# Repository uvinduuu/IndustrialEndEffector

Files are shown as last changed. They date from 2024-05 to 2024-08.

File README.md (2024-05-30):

# IndustrialEndEffector
 This project features an industrial end effector for automated pick and place robots with a vacuum gripper. It uses four ToF sensors to accurately measure box yaw and pitch angles. Data is transmitted via Modbus protocol over USB, ensuring seamless integration with robot control panels for precise orientation detection and efficient communication.

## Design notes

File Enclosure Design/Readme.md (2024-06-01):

# Industrial End Effector Enclosure Design

### Initial Approach
The primary challenge was to create an adjustable enclosure compatible with various vacuum gripper sizes. This included:
- Ensuring the TOF sensors could be repositioned.
- Providing a secure attachment method for different gripper designs.
- Balancing sensor movement with mechanical strength.

### Design Challenges and Decisions
However, we encountered several bottlenecks with this adjustable design approach:
- **Variable Vacuum Gripper Sizes:** Vacuum grippers vary significantly in size, necessitating a high degree of adjustability for the TOF sensors.
- **Attachment Method:** We needed a reliable method to attach the end effector to the gripper. Due to the varying designs of grippers, finding a universal attachment method proved difficult.
- **Sensor Movement:** The TOF sensors needed to move in two directions, adding complexity to the design.
- **Mechanical Strength:** The mechanical parts required high strength to ensure durability and stability.

### Final Design
Due to the impracticality of an adjustable design, the final implementation focused on a specific vacuum gripper model:
- **Sensor Placement:** Dedicated mounting places for TOF sensors to avoid interference with the gripper's functionality.
- **PCB Housing:** A separate box for the PCB, securely attachable to the gripper, with easy access to the USB port.
  
Image description

### Demonstration Setup
For demonstration purposes, a box will be printed to showcase the enclosure's design:
- **Sensor Mounting:** TOF sensors mounted on a board spaced 10 cm apart.
- **Enclosure Features:** Air vents for heat dissipation, mounting bosses for PCB, and a separate lid with M3 screws.



## Project Goals
- **High Precision:** Achieve accurate voltage measurements with minimal impact on the circuit under test.
- **Flexibility:** Ensure compatibility with various gripper designs without compromising performance.
- **Reliability:** Provide a stable and durable solution tailored to specific vacuum gripper models.

## How to Use
1. **Connect the Enclosure:** Securely attach the PCB enclosure to the vacuum gripper using the provided nuts.
2. **Interface with Robot Control Panels:** Utilize the USB port for data transmission via Modbus protocol.
3. **Monitor Performance:** Use the LED indicators to check the power status and ensure proper sensor operation.

## Contact
For more information or questions, please contact [mihiruth@gmail.com](mailto:mihiruth@gmail.com).

---

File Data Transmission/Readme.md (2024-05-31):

# Industrial End Effector Transmission Directory

## Overview

The measured data from tof sensors is transmitted to the robot control panel using the Modbus protocol. This provides details on the transmission part of the project, including the hardware components used and the steps for data transmission.

## What is Modbus?

Modbus is a serial communication protocol developed for industrial applications to facilitate communication between electronic devices. It is a widely used protocol in the industry due to its simplicity and reliability. Modbus allows multiple devices to communicate over a single serial connection and supports both serial and TCP/IP communications.

## Why Choose Modbus?

Modbus is chosen for this project because:
- It is a standardized protocol widely used in industrial environments.
- It supports communication over long distances with robust error checking.
- It can easily integrate with various industrial equipment and control systems.

## Hardware Components

### MAX485 TTL to RS485 Converter Module

To transmit data from the ToF sensors to the robot control panel, we use the MAX485 TTL to RS485 MAX485CSA Converter Module. This module converts the TTL level signals from the atmega2560 to RS485, which is suitable for long-distance communication.

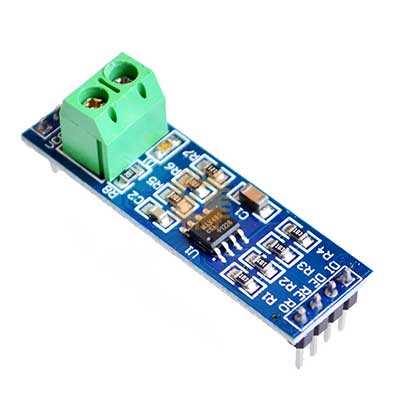
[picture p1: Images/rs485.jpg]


#### How It Happens
- The MAX485 module converts the TTL signals from the atmega2560 to differential RS485 signals.
- RS485 allows for reliable data transmission over long distances in noisy industrial environments.

#### How to Connect
2. **atmega2560 to MAX485 Module:**
   - Connect the appropriate GPIO pins of the atmega2560 (TX and RX pins, usually pins 18 and 19 for serial communication) to the input pins of the MAX485 module (DI and RO pins respectively).
   - Connect the DE (Data Enable) and RE (Receive Enable) pins of the MAX485 module to a digital pin on the atmega2560 to control the direction of data flow.
3. **MAX485 Module to RS485 Bus:**
   - Connect the RS485 output pins (A and B) of the MAX485 module to the RS485 input of the robot control panel.
4. **Power Supply:**
   - Ensure proper power supply connections to the MAX485 module from the atmega2560 or an external source.

### USB to RS485 Communication Module

For debugging purposes, we use a USB to RS485 Communication Module to connect the system to a PC.

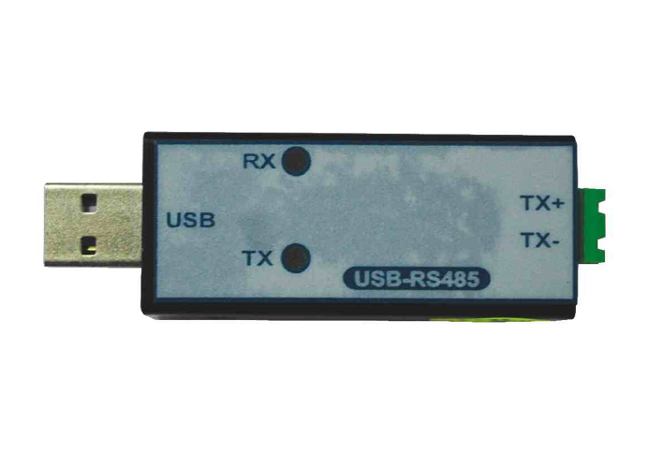
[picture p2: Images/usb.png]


#### How It Works
- The USB to RS485 module converts the USB signals from the PC to RS485 signals.
- This allows the PC to communicate with the RS485 bus, facilitating debugging and testing.

#### Why We Use It
- To monitor and debug the data being transmitted from the sensors to the robot control panel.
- To ensure that the data transmission is working correctly before final integration.

#### How to Connect
1. Connect the RS485 side of the USB to RS485 module to the RS485 bus (parallel connection with MAX485 module).
2. Plug the USB side of the module into the PC.
3. Use a terminal program or Modbus Poll software to monitor the data.

### Modbus Poll Software

For visualization, we use Modbus Poll software, a Modbus master simulator designed to monitor and test Modbus systems.

#### How It Works
- Modbus Poll allows you to send Modbus queries to the devices on the RS485 bus.
- It displays the data received from the devices, enabling real-time monitoring and testing.

#### Why We Use It
- To verify the data being transmitted by the sensors.
- To ensure the integrity and accuracy of the data before it reaches the robot control panel.

#### How to Use
1. Install Modbus Poll software on your PC.
2. Connect the PC to the RS485 bus using the USB to RS485 module.
3. Configure Modbus Poll to match the communication settings of your system (baud rate, parity, etc.).
4. Start the Modbus Poll to monitor and visualize the data.

## Conclusion

Modbus is a reliable and widely-used protocol for industrial communication, making it an excellent choice for transmitting sensor data to the robot control panel. By using the MAX485 converter module and USB to RS485 module, we ensure robust and accurate data transmission. Modbus Poll software further aids in debugging and visualization, ensuring the system functions correctly before deployment.

For more detailed technical information, feel free to contact [me](mailto:uvindukodikara@gmail.com).

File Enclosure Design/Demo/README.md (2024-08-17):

This Setup was developed for the Project Demonstration. Since we couldn't manufacture an actual vacuum gripper, we 3D printed a structure and used it for the demonstration purposes.





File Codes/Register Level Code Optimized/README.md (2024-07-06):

# Register Level Code
## Components
### Main File
- Performs calculations for the distance, pitch, and yaw of objects.
- Coordinates the overall functionality of the system.

### ToF Library
- Interfaces with the VL53L0x Time-of-Flight (ToF) sensor.
- Reads distance values from the ToF sensor.

### UART Library
- Handles serial communication using the UART protocol.
- Facilitates data transmission between the device and the Modbus converter.

### Multi-Distance Library
- Manages the multiplexer to enable the use of multiple ToF sensors.
- Retrieves distance values from several ToF sensors simultaneously.

### Delay Library
- Provides precise delay functionality.
- Ensures timing accuracy within the system.

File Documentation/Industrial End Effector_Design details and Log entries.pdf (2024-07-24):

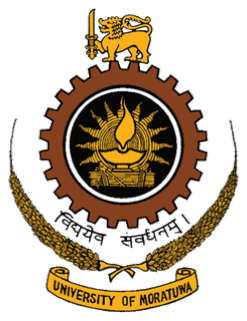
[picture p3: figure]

# University of Moratuwa, Sri Lanka

# Faculty of Engineering

## Department of Electronics and Telecommunication Engineering Semester 4 (Intake 2021)

# EN2160 - Electronic Design Realization

# Industrial End Effector - Design Details

## Group B

Kodikara U.S.S | 210293K
Gunawardane E.R.N.H. | 210200C
Sehara G.M.M. | 210583B
Kodithuwakku J.N. | 210294N

This report is submitted as a partial fulfillment for the module EN2160 - Electronic Design Realization, Department of Electronic and Telecommunication Engineering, University of Moratuwa.

## Contents

1 Comprehensive Design Details | 3
2 Final Code | 11
3 Daily Log Entries | 20

## 1 Comprehensive Design Details

### 1.1 Microcontroller Unit

The end-effector utilizes an ATmega2560 microcontroller to primarily gather readings from four sensors and perform calculations to determine the object’s distance and orientation (yaw and pitch). The ATmega2560’s capability to handle complex tasks and its compatibility with extensive sensor libraries make it an ideal choice for this application.

### 1.1.1 Distance and Orientation Measurement:

In the design of the end-effector, the ATmega2560 microcontroller plays a pivotal role in integrating sensor data and performing complex calculations to determine object distance and orientation. This microcontroller excels in managing multiple time-of-flight sensors through the I2C protocol, utilizing the Adafruit library for seamless sensor interfacing despite its extensive functionality. Here’s a detailed breakdown of its functionalities and implementation:

- Sensor Integration via I2C Protocol:

– The ATmega2560 communicates with four time-of-flight sensors using the I2C protocol, enabling efficient data transmission between the microcontroller and sensors. This protocol is chosen for its simplicity and suitability for connecting multiple sensors over short distances, ensuring reliable and synchronized data acquisition.

- Distance Measurement and Averaging:

– The The microcontroller collects distance readings from four distinct points on the object using the time-of-flight sensors. These readings are averaged to provide a precise measurement of the object’s distance from the end-effector. This averaging process enhances accuracy by mitigating potential outliers or sensor variations.

- Calculation of Pitch and Yaw:

– Using the averaged distance data, the ATmega2560 computes the object’s orientation in terms of pitch and yaw angles. This calculation involves employing inverse tangent equations to translate distance variations into angular measurements, crucial for determining the object’s spatial orientation relative to the end-effector.

- Utilization of Adafruit Library for Sensor Interface:

– The implementation leverages the Adafruit library due to its comprehensive support for sensor interfacing and data handling. Despite its heavyweight nature, the library simplifies the integration of complex sensors with the ATmega2560, streamlining development efforts and ensuring robust sensor data acquisition.

- Data Transfer via Modbus Protocol:

– After completing distance and orientation calculations, the microcontroller transfers the processed data to a Modbus converter. The Modbus protocol facilitates efficient and standardized communication between the microcontroller and external systems or devices, ensuring seamless integration into larger control or monitoring frameworks.

### 1.1.2 Programming the Microcontroller

Programming the ATmega microcontroller using the Unified Program and Debug Interface (UPDI) is a strategically advantageous approach tailored for this application. The UPDI method offers several benefits that are highly pertinent:

- Efficiency in Firmware Management: UPDI facilitates efficient uploading of firmware into the ATmega microcontroller, ensuring smooth and reliable operation of the end-effector system.
- Simplicity and Effectiveness: This programming interface is known for its straightforward implementation and effective debugging capabilities, making it easier to manage and maintain the firmware.
- Streamlined Development Process: UPDI streamlines the development process by enabling quick updates and modifications to the microcontroller’s firmware, crucial for adapting to changing project requirements or improving functionality.
- Future-Proofing and Flexibility: By using UPDI, the system becomes future-proofed, allowing for potential enhancements or adjustments in operational protocols without major hardware changes.

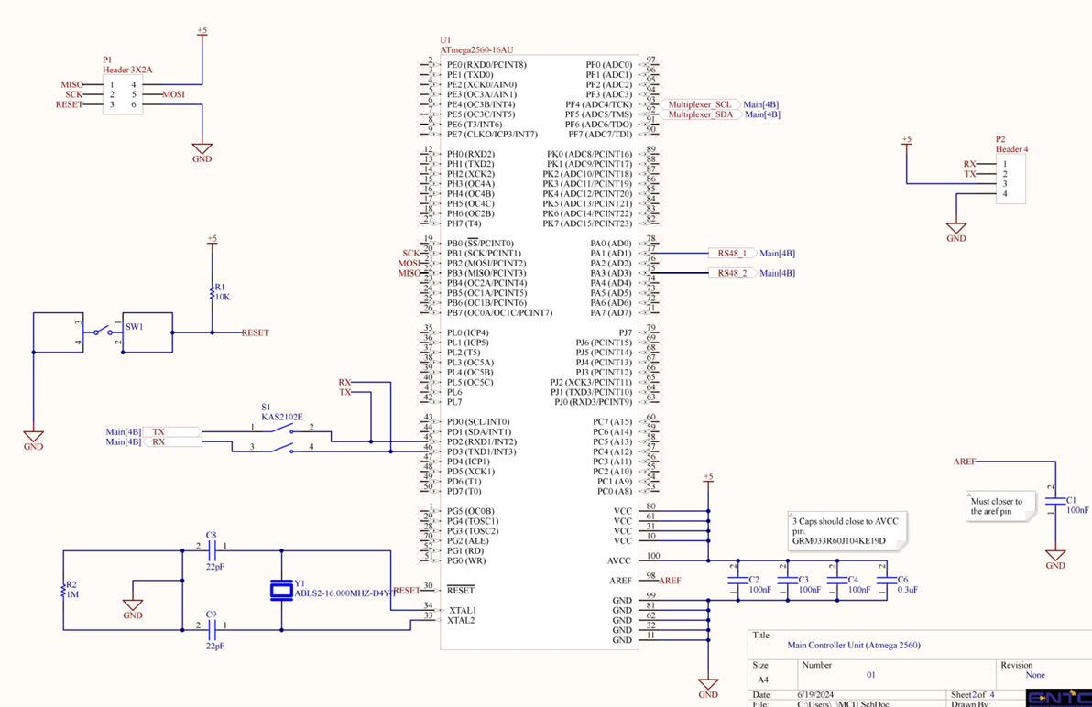
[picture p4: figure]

Figure 1: Schematic of microcontroller connections

### 1.2 Multiplexer

In optimizing the integration of multiple time-of-flight (ToF) sensors with our ATmega2560 microcontroller, we implemented the PCA9546A 1 to 4 multiplexer for streamlined I2C communication.

### 1.2.1 Why a multiplexer?

- Efficient Management of Sensor Connections:

– The PCA9546A allows us to connect up to four sensors to a single pair of SDA and SCL lines from the microcontroller.

– This consolidates multiple I2C connections into a single interface, simplifying the overall wiring layout and reducing the number of required microcontroller pins.

- Minimization of Complexity:

– By using the multiplexer, we streamline the process of interfacing multiple sensors with the microcontroller.

– It eliminates the need for additional I2C buses and complex wiring configurations, which can otherwise complicate the design and increase potential points of failure.

- Reduction of Potential Signal Interference:

– Centralizing sensor connections through the multiplexer helps minimize signal interference and crosstalk between different I2C devices.

– This ensures that data communication between the microcontroller and each sensor remains reliable and unaffected by external electrical noise.

- Enhanced Reliability of Data Acquisition:

– The PCA9546A’s ability to selectively enable communication with each sensor via its independent channels ensures reliable data acquisition.

– It provides precise control over which sensor is actively communicating with the microcontroller at any given time, optimizing data throughput and system responsiveness.

### 1.2.2 Hardware Components

The PCA9546A is a versatile I2C multiplexer designed to enable communication with multiple I2C devices using a single microcontroller interface. It features four independent channels that can be selected via control registers, effectively routing data and clock signals to different I2C buses connected to various sensors. This flexibility makes it ideal for applications requiring efficient management of multiple I2C devices without the need for additional microcontroller pins or complex wiring.

How it is connected

- atmega2560 to multiplexer

– The main SDA (data) and SCL (clock) lines from the ATmega2560 microcontroller are connected directly to the PCA9546A multiplexer.

- multiplexer to the ToF sensors

– The PCA9546A multiplexer features four independent channels, each capable of connecting to a separate I2C bus.

– Each ToF sensor module is connected to one of these channels on the multiplexer, establishing a dedicated communication path between the microcontroller and each sensor.

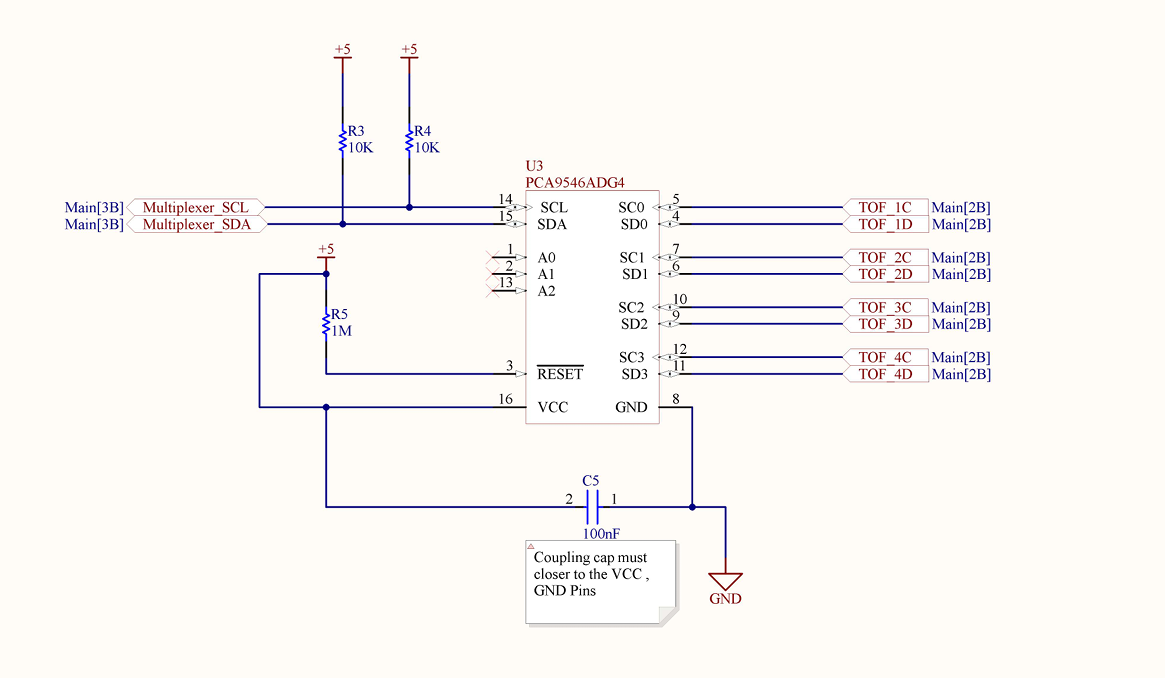
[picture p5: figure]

Figure 2: Schematic of PCA9546A connections

### 1.3 Time of Flight Sensors

### 1.3.1 Implementation of the Time of Flight Sensors

For the end-effector application, selecting VL53L0X Time-of-Flight (ToF) sensors was crucial for achieving accurate distance measurements from four distinct points on objects. These sensors, renowned for their precision and ease of integration, utilize the I2C communication protocol for seamless interfacing with our ATmega2560 microcontroller. By directly connecting these sensors to a PCA9546A multiplexer, we efficiently manage communication channels while maintaining high measurement accuracy.

### 1.3.2 Why VL53L0X?

he VL53L0X ToF sensor module is a compact and highly accurate device designed specifically for distance measurement applications. It operates by emitting short pulses of infrared light and measuring the time it takes for these pulses to reflect off a target surface and return to the sensor. This time-of-flight measurement directly correlates to the distance between the sensor and the object being measured. The sensor employs advanced algorithms within its internal processing unit to calculate distances with exceptional precision, achieving resolutions down to millimeters. This method ensures consistent and reliable performance across diverse environmental conditions, making the VL53L0X ideal for applications requiring precise and robust distance measurements. Some advantages of the implementation of VL53L0X are,

- High Accuracy: Provides precise distance measurements with resolutions as fine as millimeters, ensuring reliable data for critical applications.
- Compact Size: Small form factor makes it suitable for integration into compact or spaceconstrained devices and systems.
- Wide Measurement Range: Offers a wide range of measurement distances, accommodating diverse application needs from short to long distances.
- Easy Integration: Supports simple integration into existing systems with straightforward I2C communication protocol and user-friendly interfaces.

### 1.3.3 Hardware Connections

- Direct Connection to Multiplexer Channels:

– Each VL53L0X sensor module is connected directly to one of the output channels of the PCA9546A multiplexer.

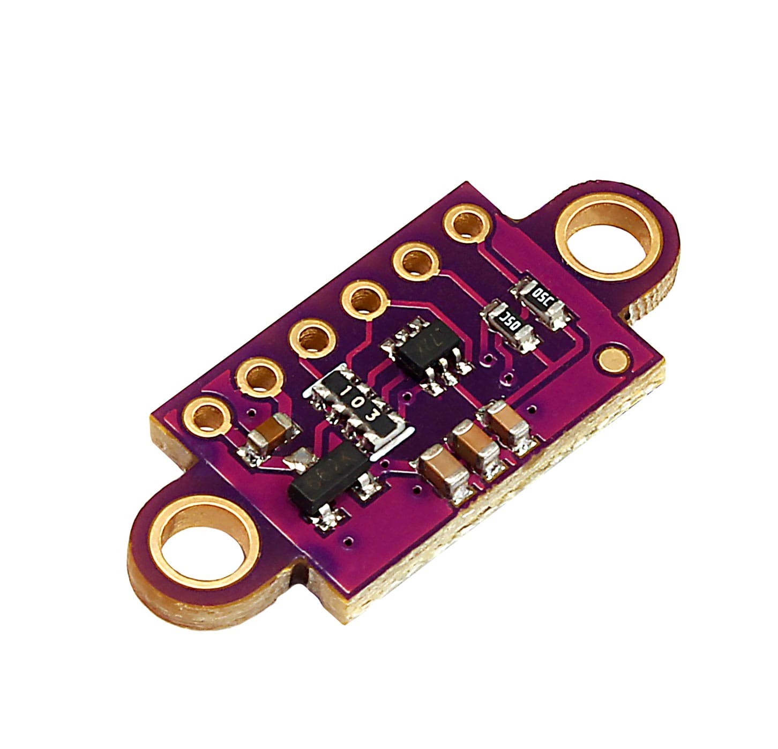
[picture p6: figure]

Figure 3: VL53L0X Sensor Module

### 1.4 Modbus Transmitter

In the development of an industrial end effector, particularly for a vacuum gripper, precise and reliable transmission of sensor data is crucial. Our project employs four Time of Flight (ToF) sensors to measure pitch and yaw angles, with the data transmitted to the robot control panel using the Modbus protocol. This section details the transmission component of the project, covering hardware and data transmission steps.

### 1.4.1 Implementation of Modbus Communication

Modbus is a serial communication protocol designed for industrial applications, facilitating communication between electronic devices. Its simplicity, reliability, and support for both serial and TCP/IP communications make it an excellent choice for our project.

### 1.4.2 Why Choose Modbus?

- Standardization: Widely used in industrial environments.
- Distance and Reliability: Supports long-distance communication with robust error checking.
- Integration: Easily integrates with various industrial equipment and control systems.

### 1.4.3 Hardware Components

MAX485 TTL to RS485 Converter Module
To transmit data from the ToF sensors to the robot control panel, we use the MAX485 TTL to RS485 MAX485CSA Converter Module. This module converts TTL level signals from the sensors to RS485, suitable for long-distance communication.

How It Works

The MAX485 module converts the TTL signals from the sensors to differential RS485 signals, enabling reliable data transmission over long distances in noisy industrial environments.

How to Connect

- atmega2560 to MAX485 Module:

– Connect the appropriate GPIO pins of the atmega2560 (TX and RX pins, usually pins 18 and 19 for serial communication) to the input pins of the MAX485 module (DI and RO pins respectively).

– Connect the DE (Data Enable) and RE (Receive Enable) pins of the MAX485 module to a digital pin on the Arduino Mega to control the direction of data flow.

- MAX485 Module to RS485 Bus:

– Connect the RS485 output pins (A and B) of the MAX485 module to the RS485 input of the robot control panel.

- Power Supply:

– Ensure proper power supply connections to the MAX485 module from the Arduino Mega or an external source.

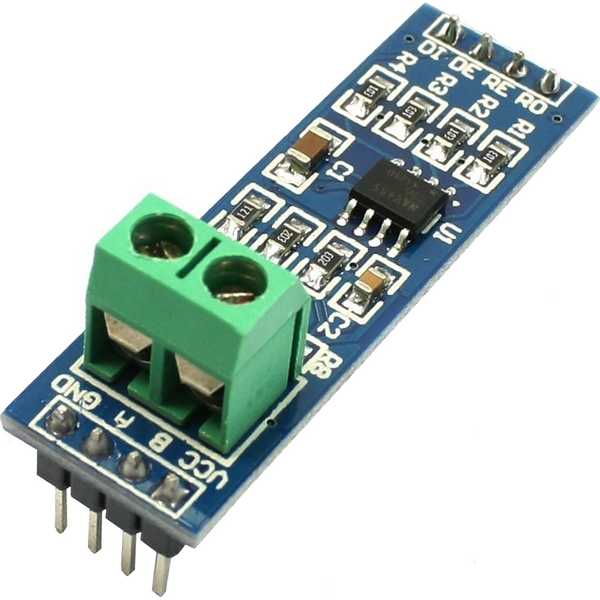
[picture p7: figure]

Figure 4: MAX485 TTL to RS485 Converter Module

### 1.5 Testing and Demonstration

In the end effector, we utilize the Modbus protocol to communicate with the robot arm. However, for testing and debugging purposes, we need to display the calculated pitch and yaw angles from our end effector. Since these values are transmitted using the Modbus protocol, they cannot be directly observed on the computer interface. Therefore, we employ an RS485 to USB converter module along with Modbus Poll software. This setup is essential solely for demonstration and testing purposes.

### 1.5.1 USB to RS485 Communication Module

Functionality
The USB to RS485 Communication Module is essential for converting Modbus protocol signals from the RS485 bus into a format compatible with USB, enabling data display and interaction on a computer.

Operational Mechanism

- Signal Conversion:

– Converts Modbus protocol signals from RS485 to USB format, facilitating direct communication between the RS485 bus and a computer.

- Display Compatibility:

– Enables the display and interaction of received data from RS485 devices on a computer interface via USB port of the computer.

- Diagnostic and Debugging Tool:

– Used extensively for monitoring and debugging data transmissions between sensors, the end effector, and the computer; ensuring clear and accurate display of data received via Modbus protocol on a computer screen.

Connection Procedure:

- Connect the RS485 side of the ’USB to RS485 module’ to the ’MAX485 TTL to RS485 Converter Module’.
- Plug the USB side of the module into a computer, establishing a direct interface for data display and interaction.

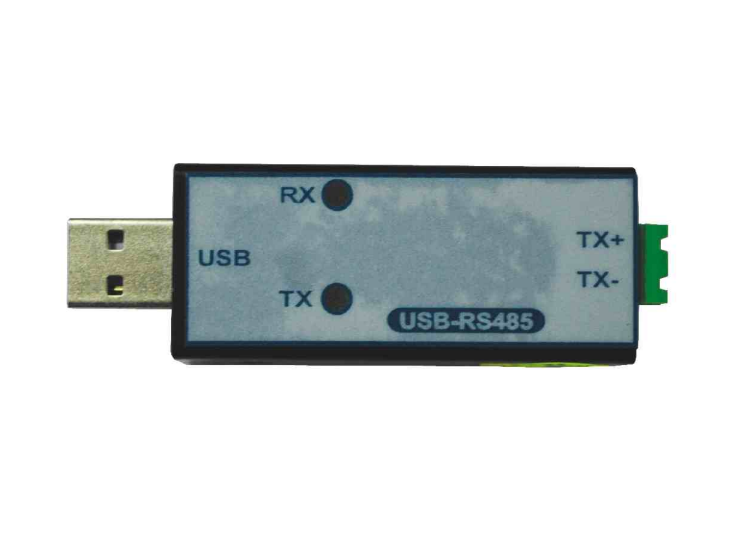
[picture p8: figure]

Figure 5: USB to RS485 Communication Module

### 1.5.2 Modbus poll software

Functionality
Modbus Poll software serves as a Modbus master simulator designed for monitoring and testing Modbus systems. It facilitates visualization and interaction with data exchanged over the RS485 bus.

Operational Mechanism

- Data Monitoring:

– Allows users to send Modbus queries to devices connected on the RS485 bus.

- Real-time Display:

– Displays data received from connected devices, enabling real-time monitoring and testing of Modbus communications.

- Diagnostic and Debugging Tool:

– Essential for verifying data accuracy, integrity, and transmission reliability before it reaches the robot control panel, ensuring the data transmitted by sensors is accurate and consistent.

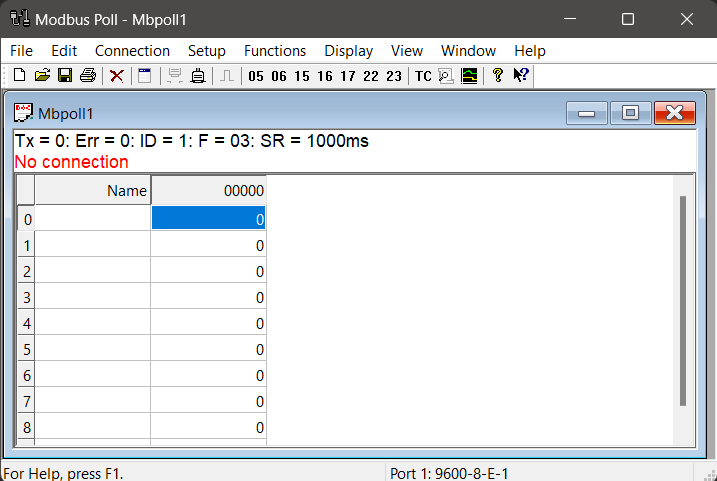
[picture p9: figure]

Figure 6: Modbus Poll Software

## 2 Final Code

# include < avr / io .h >

# include " delay .h"

# include " uart .h"

# include "TWI.h"

# include "ToF.h"

# include " multi_distance .h"

// // below values should be configured
float dv = 41; // vertical distance between the ToF sensors
float dhu = 76; // horizontal distance between the upper ToF sensors float dhd = 76; // horizontal distance between the lower ToF sensors

// // below values are read and calculated
float relativeDistance ;
float dlu ; // left upper ToF sensor distance float dru ; // right upper ToF sensor distance
float dld ; // left down ToF sensor distance
float drd ; // right down ToF sensor distance
float thetaP ; // pitch angle ( angle around the horizontal axis ) float thetaY ; // yaw angle ( angle around the vertical axis )

int main () {
init_uart () ; // Intializing the Serial communication with UART protocol i2c_init () ; // Intializing TWI
setID () ; // Intializing the multiplexer and the ToF sensors
init_rs485 () ; // Initialize RS485 pins

while (1) {
dlu = 0;
dru = 0;
dld = 0;
drd = 0;

for (int i =0; i <5; i ++) { // Implementation of the moving average filter dlu += sensor_1 () - 5;
dru += sensor_2 () ;
dld += sensor_3 () ;
drd += sensor_4 () - 4;
delay_ms (10) ;

}

dlu = dlu /5;
dru = dru /5;
dld = dld /5;
drd = drd /5;

relativeDistance = ( dlu + dru + dld + drd ) /4;

thetaP = 0.5* atan (( dlu - dld ) / dv ) + 0.5* atan (( dru - drd ) / dv ) ; // Calculating the Pitch
thetaY = 0.5* atan (( dru - dlu ) / dhu ) + 0.5* atan (( drd - dld ) / dhd ) ; // Calculating the Yaw thetaP = degrees ( thetaP ) ;
thetaY = degrees ( thetaY ) ;

trans_string (" Relative Distance : ") ; trans_num ( relativeDistance ) ; trans_string (" Pitch Angle : ") ; trans_num ( thetaP ) ;
trans_string (" Yaw Angle : ") ; trans_num ( thetaY ) ;
trans_string ("\n") ;

// Write angles as floats to Modbus registers modbus_write_float_registers ( MODBUS_SLAVE_ID , 0 x0000 , thetaP ) ; // Write thetaP as float to registers 0 and 1
delay_ms (100) ;
modbus_write_float_registers ( MODBUS_SLAVE_ID , 0 x0002 , thetaY ) ; // Write thetaY as float to registers 2 and 3

delay_ms (1000) ;

}

return 0;

}

Listing 1: Main Code

# define VL53L1X_ADDR 0 x52 // Defining the ToF Address

void vl53l1x_init () {
// Initializing the ToF
i2c_start () ;
i2c_write ( VL53L1X_ADDR ) ; // Device address i2c_write (0 x00 ) ; // Default register address i2c_write (0 x01 ) ;
i2c_stop () ;

}

void vl53l1x_measure_distance () {
i2c_start () ;
i2c_write ( VL53L1X_ADDR ) ; // Device address i2c_write (0 x00 ) ;
i2c_write (0 x02 ) ; // Setting the measuring mode i2c_stop () ;

}

uint16_t vl53l1x_read_distance () { uint16_t distance ;

// Read distance high byte
i2c_start () ;
i2c_write ( VL53L1X_ADDR ) ; // Device address
i2c_write (0 x14 + 10) ; // Register address for distance high byte i2c_start () ; // Repeated start

29 | i2c_write ( VL53L1X_ADDR | 0 x01 ) ; // Read mode
30 | uint8_t high_byte = i2c_read_ack () ;

31
32 | // Read distance low byte
33 | uint8_t low_byte = i2c_read_nack () ;
34 | i2c_stop () ;

35
36 | distance = ( high_byte << 8) | low_byte ;
37 | // distance = low_byte ;

38
39 | return distance ;
40 | }

Listing 2: ToF Library

1 | # ifndef ToF
2 | # define ToF

3
4 | # include < avr / io .h >
5 | # include "TWI.h"

6
7 | void vl53l1x_init () ;
8 | void vl53l1x_measure_distance () ;
9 | uint16_t vl53l1x_read_distance () ;

10
11 # endif

Listing 3: ToF Header File

1 | void i2c_init () {
2 | // Set the clock speed
3 | TWSR = 0 x00 ;
4 | TWBR = (( F_CPU /400000) -16) /(2* pow (4 ,( TWSR &((1 < < TWPS0 ) |(1 < < TWPS1 ) ) ) ) ) ;
5 | }

6
7 | void i2c_start () {
8 | // Send start condition
9 | TWCR = (1 << TWSTA ) | (1 << TWEN ) | (1 << TWINT ) ;
10 | while (!( TWCR & (1 << TWINT ) ) ) ;
11 | }

12
13 | void i2c_stop () {
14 | // Send stop condition
15 | TWCR = (1 << TWSTO ) | (1 << TWEN ) | (1 << TWINT ) ;
16 | }

17
18 | void i2c_write ( uint8_t data ) {
19 | // Write data to the I2C bus
20 | TWDR = data ;
21 | TWCR = (1 << TWEN ) | (1 << TWINT ) ;
22 | while (!( TWCR & (1 << TWINT ) ) ) ;
23 | }

24
25 | uint8_t i2c_read_ack () {
26 | // Read data from the I2C bus with acknowledgment
27 | TWCR = (1 << TWEN ) | (1 << TWINT ) | (1 << TWEA ) ;

28 | while (!( TWCR & (1 << TWINT ) ) ) ;
29 | return TWDR ;
30 | }

31
32 | uint8_t i2c_read_nack () {
33 | // Read data from the I2C bus without acknowledgment
34 | TWCR = (1 << TWEN ) | (1 << TWINT ) ;
35 | while (!( TWCR & (1 << TWINT ) ) ) ;
36 | return TWDR ;
37 | }

Listing 4: TWI Library

1 | # ifndef TWI
2 | # define TWI

3
4 # include < avr / io .h >

5
6 | void i2c_init () ;
7 | void i2c_start () ;
8 | void i2c_stop () ;
9 | void i2c_write ( uint8_t data ) ;
10 | uint8_t i2c_read_ack () ;
11 | uint8_t i2c_read_nack () ;

12
13 # endif

Listing 5: TWI Header File

1 | // receive one byte data
2 | unsigned char USART_Receive ()
3 | {
4 | while (!( UCSR0A & (1 < < RXC0 ) ) ) ; | // receive buffer empty
5 | return UDR0 ; // receive reg
6 | }

7

8
9 | // transmit one byte
10 | void UART_Txchar ( char ch )
11 | {
12 | while (!( UCSR0A & (1 < < UDRE0 ) ) ) ; // WAIT UNTIL EMPTY TRANSMIT BUFFER
13 | UDR0 = ch ; // after transmit buffer empty load data to the uart data
| register

14

15 }

16

17
18 | // transmit string
19 | void trans_string ( char str []) {
20 | int lenght = strlen ( str ) ;
21 | char trans ;
22 | for(int i =0; i < lenght ; i ++) {
23 | trans = str [ i ];
24 | UART_Txchar ( trans ) ;
25 | }
26 | }

27
28 | // transmit number
29 | void trans_num ( uint16_t num ) {
30 | String number = String ( num ) ;
31 | int lenght = number . length () ;
32 | char trans ;
33 | for(int i =0; i < lenght ; i ++) {
34 | trans = number [ i ];
35 | UART_Txchar ( trans ) ;
36 | }
37 | // UART_Txchar ( ’\n ’);
38 | }

39
40 | void init_uart () {
41 | // Enable transmitter and recirever bits - Use USART0

42
43 UCSR0B |= (1 < < RXEN0 ) | (1 < < TXEN0 ) ; // ENABLE RX AND RX

44
45 | // SET THE DATA SIZE FOR COMMUNIATION
46 | UCSR0C &= (~(1 < < UMSEL00 ) ) & (~(1 < < UMSEL01 ) ) ; | // ENABLE ASYNCHRONOUS
USART COMMUNICATION
47 | UCSR0C &= (~(1 < < UPM00 ) ) & (~(1 < < UPM01 ) ) ; | // DISABLE PARITY BIT
48 | UCSR0C &= (~(1 < < USBS0 ) ) ; // CHOOSE ONE STOP BIT

49
50 | // SET DATA LENGHT TO BE 8 BITS
51 | UCSR0B &= (~(1 < < UCSZ02 ) ) ;
52 | UCSR0C |= (1 < < UCSZ00 ) | (1 < < UCSZ01 ) ; | // SET 8 BITS 011 BITS IN UCSZ02 ,
UCSZ00 , UCSZ01

53
54 // SET THE SPEED FOR TRANSMISSION

55
56 | UCSR0A |= (1 < < U2X0 ) ; // SELSCT HIGH SPEED MODE
57 | // UCSR0A &= ~(1 < < U2X0 ); // low speed

58
59 | // BAUDRATE
60 | UBRR0 = 207; // 9600 BAUDRATE FROM DATASHEET DIRECT TABLE FOR U2X0 =1 if
u2x =0 , ubrr0 = 103

61 }

Listing 6: UART Library

1 | # ifndef UART
2 | # define UART

3
4 # include < avr / io .h >

5
6 | unsigned char USART_Receive () ;
7 | void UART_Txchar ( char ch ) ;
8 | void trans_string ( char str []) ;
9 | void trans_num ( uint16_t num ) ;
10 | void init_uart () ;

11
12 # endif

Listing 7: UART Header File

1 | void TCA9548A ( uint8_t bus ) { // Initializing the multiplexer channel
2 | i2c_start () ;
3 | i2c_write (0 x70 ) ;
4 | i2c_write ( bus ) ;
5 | i2c_write (0 x01 ) ;
6 | i2c_stop () ;
7 | }

8
9 void setID () { // Initializing the ToF sensors

10
11 | TCA9548A (0) ;
12 | vl53l1x_init () ;

13
14 | TCA9548A (1) ;
15 | vl53l1x_init () ;

16
17 | TCA9548A (2) ;
18 | vl53l1x_init () ;

19
20 | TCA9548A (3) ;
21 | vl53l1x_init () ;
22 | }

23
24 | float sensor_1 () { // Getting sensor 1 reading
25 | TCA9548A (0) ;
26 | vl53l1x_measure_distance () ;
27 | return ( float ) vl53l1x_read_distance () ;
28 | }
29 | float sensor_2 () { // Getting sensor 2 reading
30 | TCA9548A (1) ;
31 | vl53l1x_measure_distance () ;
32 | return ( float ) vl53l1x_read_distance () ;
33 | }

34
35 | float sensor_3 () { // Getting sensor 3 reading
36 | TCA9548A (2) ;
37 | vl53l1x_measure_distance () ;
38 | return ( float ) vl53l1x_read_distance () ;
39 | }

40
41 | float sensor_4 () { // Getting sensor 4 reading
42 | TCA9548A (3) ;
43 | vl53l1x_measure_distance () ;
44 | return ( float ) vl53l1x_read_distance () ;
45 | }

Listing 8: Multiplexer Library

1 | # ifndef MULTI
2 | # define MULTI

3
4 | # include < avr / io .h >
5 | # include "TWI.h"
6 | # include "ToF.h"

7
8 | void TCA9548A ( uint8_t bus ) ;
9 | void setID () ;
10 | float sensor_1 () ;
11 | float sensor_2 () ;
12 | float sensor_3 () ;
13 | float sensor_4 () ;

14
15 # endif

Listing 9: Multiplexer Header File

1 | void delay_ms ( unsigned int ms ) {
2 | for ( unsigned int i = 0; i < ms ; i ++) {
3 | // Configure Timer1
4 | TCCR1A = 0; | // Clear Timer1 Control Register A
5 | TCCR1B = 0; | // Clear Timer1 Control Register B
6 | TCNT1 = 0; | // Clear Timer1 Counter

7
8 | // Set Timer1 to CTC mode and set prescaler to 64
9 | TCCR1B |= (1 << WGM12 ) | (1 << CS11 ) | (1 << CS10 ) ;

10
11 | // Set compare match register for 1ms delay
12 | OCR1A = 249;

13
14 | // Wait for compare match flag to be set
15 | while (!( TIFR1 & (1 << OCF1A ) ) ) ;

16
17 | // Clear compare match flag
18 | TIFR1 |= (1 << OCF1A ) ;
19 | }
20 | }

Listing 10: Delay Library

1 | # ifndef DELAY
2 | # define DELAY

3
4 # include < avr / io .h >

5
6 void delay_ms ( unsigned int ms ) ;

7
8 # endif

Listing 11: Delay Header File

1 | // Define Modbus Slave ID
2 | # define MODBUS_SLAVE_ID 1

3
4 | // Define RS485 pins
5 | # define MAX485_DE | PB0
6 | # define MAX485_RE_NEG | PB1

7
8 | // Initialize RS485 pins
9 | void init_rs485 () {
10 | DDRB |= (1 << MAX485_DE ) | (1 << MAX485_RE_NEG ) ;

PORTB &= ~(1 << MAX485_DE ) ; PORTB &= ~(1 << MAX485_RE_NEG ) ;

}

// Enable RS485 transmit mode void enable_transmit () {
PORTB |= (1 << MAX485_DE ) ; PORTB |= (1 << MAX485_RE_NEG ) ;

}

// Enable RS485 receive mode void enable_receive () {
PORTB &= ~(1 << MAX485_DE ) ; PORTB &= ~(1 << MAX485_RE_NEG ) ;

}

// Function to calculate CRC for Modbus
uint16_t calculate_crc ( uint8_t * buffer , uint8_t length ) { uint16_t crc = 0 xFFFF ;
for (int pos = 0; pos < length ; pos ++) {
crc ^= ( uint16_t ) buffer [ pos ];
for (int i = 8; i != 0; i - -) {
if (( crc & 0 x0001 ) != 0) {
crc > >= 1;
crc ^= 0 xA001 ;
} else {
crc > >= 1;

}

}

}
return crc ;

}

// Function to write two consecutive registers with a float value void modbus_write_float_registers ( uint8_t id , uint16_t address , float value ) {
union {
float f ;
uint16_t parts [2];
} float_converter ;

float_converter . f = value ;

// Send high part
modbus_write_single_register ( id , address , float_converter . parts [1]) ; delay_ms (100) ;

// Send low part
modbus_write_single_register ( id , address + 1 , float_converter . parts [0]) ; delay_ms (100) ;

}

// Function to write a single register on Modbus void modbus_write_single_register ( uint8_t id , uint16_t address , uint16_t value ) {
uint8_t frame [8];
uint16_t crc ;

frame [0] = id ; // Slave ID from the robot controller frame [1] = 0 x06 ; // Function code ( Write Single Register ) frame [2] = ( address >> 8) & 0 xFF ; // Address high byte frame [3] = address & 0 xFF ; // Address low byte
frame [4] = ( value >> 8) & 0 xFF ; // Value high byte
frame [5] = value & 0 xFF ; // Value low byte

crc = calculate_crc ( frame , 6) ;
frame [6] = crc & 0 xFF ; // CRC low byte
frame [7] = ( crc >> 8) & 0 xFF ; // CRC high byte

enable_transmit () ;
for (int i = 0; i < 8; i ++) {
UART_Txchar ( frame [ i ]) ; // Transmit each byte of the frame over UART

}
enable_receive () ;

}

Listing 12: Modbus Library

# ifndef MODBUS

# define MODBUS

# include < stdint .h >

# include < avr / io .h >

# include " uart .h"

// Define Modbus Slave ID
# define MODBUS_SLAVE_ID 1

// Define RS485 pins
12 | # define MAX485_DE | PB0
13 | # define MAX485_RE_NEG | PB1

// Function declarations
| void init_rs485 () ;
| void enable_transmit () ;
| void enable_receive () ;
void modbus_write_float_registers ( uint8_t id , uint16_t address , float
| value ) ;
void modbus_write_single_register ( uint8_t id , uint16_t address , uint16_t
| value ) ;

// Function to calculate CRC for Modbus
uint16_t calculate_crc ( uint8_t * buffer , uint8_t length ) ;
| # endif

Listing 13: Modbus Header File

## 3 Daily Log Entries

## Week 1 (Background Research)

### 3.1 February 18, 2024

We began our project by conducting initial background research on robotic depalletizing systems, focusing on two primary resources recommended by our professor. The first resource was a YouTube video titled ”A Re configurable Gripper for Robotic Autonomous Depalletizing” which provided an overview of innovative gripper technology designed for supermarket logistics. This video highlighted key aspects such as the gripper’s ability to handle various box shapes and weights through its re configurable design, and the integration of sensors for adaptive grasping.

### 3.2 February 21, 2024

We involved a detailed review of the academic paper titled ”A Reconfigurable Gripper for Robotic Autonomous Depalletizing in Supermarket Logistics,” published in IEEE Robotics and Automation Letters. This paper, authored by G. Andrea Fontanelli et al., detailed the technical specifications and operational principles of the reconfigurable gripper. Key insights included the gripper’s mechanical structure, sensor integration, and adaptive capabilities which allow it to handle different sizes and weights of boxes, enhancing efficiency in unstructured environments like supermarkets.

### 3.3 February 23, 2024

We compared insights from both the video and the paper, identifying additional technologies used in robotic depalletizing systems. These technologies include Time-of-Flight (ToF) sensors, Kinect sensors employing computer vision, and mechanical probes. ToF sensors measure distance by calculating the time it takes for a light signal to reflect off an object and return. Kinect sensors use computer vision to create 3D maps of the environment, aiding in object detection and manipulation. Mechanical probes physically interact with objects to determine their dimensions and orientation. These technologies offer different approaches to enhancing robotic precision and adaptability in various industrial settings.

## Week 2 (Comparing Different Approaches)

### 3.4 February 26, 2024

We focused on comparing different technological approaches for our robotic depalletizing system. On the first day, we explored the use of VL53L0X Time-of-Flight (ToF) sensors to measure pitch and yaw angles. The VL53L0X sensors work by emitting a laser pulse and measuring the time it takes for the pulse to return after reflecting off an object. This time measurement is then used to calculate the distance to the object. To measure pitch and yaw angles, we configured four VL53L0X ToF sensors positioned at known distances apart. By analyzing the distance data from these sensors, we can calculate the angles based on the differences in distance measurements. This method requires precise placement of the sensors to ensure accurate angle calculations, and it proved effective but required careful alignment and calibration.

### 3.5 February 29, 2024

Then we explored the use of Lidar sensors for measuring pitch and yaw angles. Lidar, which stands for Light Detection and Ranging, uses laser pulses to create detailed 3D maps of the environment.

A Lidar sensor scans the surroundings by emitting laser beams and measuring the time it takes for each beam to return after hitting an object. This process results in a high-resolution point cloud that represents the spatial characteristics of the environment. For our application, we can use Lidar to measure pitch and yaw angles by analyzing the spatial data it provides. The Lidar sensor can detect the orientation and position of objects more comprehensively than individual ToF sensors, making it a robust option for capturing detailed environmental information.

### 3.6 March 1, 2024

We compared the pros and cons of using VL53L0X ToF sensors versus Lidar sensors for our project, focusing on cost and practical arrangement. VL53L0X ToF sensors are relatively inexpensive and easy to integrate but require precise positioning and calibration, which can be challenging in a dynamic industrial setting. Lidar sensors, on the other hand, provide more comprehensive data and require less meticulous placement but are significantly more expensive. After considering these factors, we concluded that using VL53L0X ToF sensors is the more effective solution for our project. Their lower cost and sufficient accuracy for our application outweigh the benefits of the more detailed but expensive Lidar sensors. This decision aligns with our project’s budget constraints and operational requirements, ensuring a practical and cost-effective implementation.

## Week 3 (Comparing Different Approaches)

### 3.7 March 5, 2024

Then we explored the use of Kinect sensors for measuring pitch and yaw angles using computer vision techniques. Kinect sensors, originally designed for gaming, have become popular in various fields for their ability to capture depth and motion. The sensor uses an infrared projector combined with a monochrome CMOS sensor to capture 3D data. For our application, the Kinect sensor captures a detailed depth map of the environment. By processing this depth data with computer vision algorithms, we can calculate the pitch and yaw angles of objects. The Kinect’s ability to capture both depth and color information allows for robust and detailed environmental analysis, providing comprehensive spatial data that can be used to determine the orientation and position of objects with high precision.

### 3.8 March 9, 2024

We compared the pros and cons of using Kinect sensors versus VL53L0X ToF sensors and Lidar sensors for our project, focusing on cost and practical arrangement. Kinect sensors offer the advantage of capturing rich 3D data along with color information, which can be beneficial for more complex analysis and applications beyond simple distance measurements. However, they tend to be bulkier and require more computational power to process the data. Additionally, Kinect sensors are more sensitive to environmental lighting conditions compared to ToF sensors. Despite these limitations, the Kinect’s ability to provide comprehensive data makes it a strong candidate for applications requiring detailed environmental mapping. However, due to its higher cost and complexity in integration, we determined that VL53L0X ToF sensors remain the more practical and cost-effective choice for our specific needs, offering sufficient accuracy and ease of integration within our project’s budget and operational constraints.

## Week 4 (Enclosure Arrangement)

### 3.9 March 11, 2024

Today, our team collectively drew and analyzed four conceptual enclosure designs. Each member contributed to the brainstorming session, and together we evaluated these designs based on specific criteria. This collaborative effort allowed us to discuss the strengths and challenges of each concept, guiding us towards refining our enclosure design strategy effectively.

## Week 5 (Implementation of the code)

### 3.10 March 17, 2024

We focused on developing an algorithm to measure the distance, yaw, and pitch of an object using distance readings from four sensors placed at the corners of a rectangular shape. Utilizing the following equations, which are derived from the referenced research paper, we were able to achieve our measurements:

θp =

1
2

tan⁻¹

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
tan⁻¹

Dru
Dv

·

Drd
Dv
(1)

θy =

1
2

tan⁻¹

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
tan⁻¹

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
(Dlu + Dru + Dld + Drd) | (3)

Where:

- θp is the pitch angle,
- θy is the yaw angle,
- D is the average distance,
- Dlu, Dld, Dru, Drd are the distance readings from the upper-left, lower-left, upper-right, and lower-right sensors respectively,
- Dv is a vertical reference distance,
- Dhu, Dhd are horizontal reference distances for the upper and lower sensors.

## Initial Code - Implemented using Arduino

# include " distance .h"

# include < ModbusRtu .h >

# define MODBUS_SLAVE_ID 1 # define MAX485_DE 10

# define MAX485_RE_NEG 11

Modbus slave ( MODBUS_SLAVE_ID , Serial , 0) ;

uint16_t modbus_regs [10];

// Below values should be configured
float dv = 41; // vertical distance between the ToF sensors
float dhu = 76; // horizontal distance between the upper ToF sensors float dhd = 76; // horizontal distance between the lower ToF sensors

// Below values are read and calculated
float relativeDistance ;
float dlu ; // left upper ToF sensor distance float dru ; // right upper ToF sensor distance
float dld ; // left down ToF sensor distance
float drd ; // right down ToF sensor distance
float thetaP ; // pitch angle ( angle around the horizontal axis ) float thetaY ; // yaw angle ( angle around the vertical axis )

void setup () {
// Initialization
Serial . begin (9600) ;
pinMode ( MAX485_DE , OUTPUT ) ; pinMode ( MAX485_RE_NEG , OUTPUT ) ; setID () ;
slave . begin (9600) ;

}

void loop () {
dlu = 0;
dru = 0;
dld = 0;
drd = 0;

for (int i = 0; i < 5; i ++) { // Implementation of the moving average filter
dlu += sensor_1 () - 5;
dru += sensor_2 () ;
dld += sensor_3 () ;
drd += sensor_4 () - 4;
delay (10) ;

}

dlu = dlu / 5;
dru = dru / 5;

dld = dld / 5;
drd = drd / 5;

relativeDistance = ( dlu + dru + dld + drd ) / 4;

thetaP = 0.5 * atan (( dlu - dld ) / dv ) + 0.5 * atan (( dru - drd ) / dv ) ; thetaY = 0.5 * atan (( dru - dlu ) / dhu ) + 0.5 * atan (( drd - dld ) / dhd ) ;

thetaP = degrees ( thetaP ) ;
thetaY = degrees ( thetaY ) ;

Serial . print (" Relative Distance : " + String ( relativeDistance ) + " ") ; Serial . print (" Pitch Angle : " + String ( thetaP ) + " ") ;
Serial . println ("Yaw Angle : " + String ( thetaY ) + " ") ;

// Store angles in Modbus registers
modbus_regs [0] = ( uint16_t ) ( thetaP * 100) ; modbus_regs [1] = ( uint16_t ) ( thetaY * 100) ;

// Enable RS485 transmit mode digitalWrite ( MAX485_DE , HIGH ) ;
digitalWrite ( MAX485_RE_NEG , HIGH ) ;

slave . poll ( modbus_regs , 2) ;

// Enable RS485 receive mode digitalWrite ( MAX485_DE , LOW ) ; digitalWrite ( MAX485_RE_NEG , LOW ) ;

delay (1000) ;

}

Listing 14: Main code

# include < Adafruit_VL53L0X .h > # include < Wire .h >

# include < Arduino .h >

int sensor1 , sensor2 , sensor3 , sensor4 ; float sensor_readings [4] = { 0 , 0 , 0 , 0};

// objects for the vl53l0x Adafruit_VL53L0X lox1 = Adafruit_VL53L0X () ; Adafruit_VL53L0X lox2 = Adafruit_VL53L0X () ; Adafruit_VL53L0X lox3 = Adafruit_VL53L0X () ; Adafruit_VL53L0X lox4 = Adafruit_VL53L0X () ;

// this holds the measurement VL53L0X_RangingMeasurementData_t measure1 ; VL53L0X_RangingMeasurementData_t measure2 ; VL53L0X_RangingMeasurementData_t measure3 ; VL53L0X_RangingMeasurementData_t measure4 ;

/*
Reset all sensors by setting all of their XSHUT pins low for delay (10)

, then set all XSHUT high to bring out of reset
Keep sensor #1 awake by keeping XSHUT pin high
Put all other sensors into shutdown by pulling XSHUT pins low Initialize sensor #1 with lox. begin ( new_i2c_address ) Pick any number but 0x29 and it must be under 0x7F. Going with 0x30 to 0x3F is probably OK.
Keep sensor #1 awake , and now bring sensor #2 out of reset by setting its XSHUT pin high .
Initialize sensor #2 with lox. begin ( new_i2c_address ) Pick any number but 0x29 and whatever you set the first sensor to

*/

void TCA9548A ( uint8_t bus ) {
30 | Wire . beginTransmission (0 x70 ) ; | // TCA9548A address is 0x70
31 | Wire . write (1 << bus ) ; | // send byte to select bus
| Wire . endTransmission () ;

}

| void setID () {
| // initing LOX1
| TCA9548A (0) ;
| if (! lox1 . begin (0 x29 ) ) {
// Serial . println (F(" Failed to boot first VL53L0X "));
| while (1)
| ; }
| // initing LOX2
| TCA9548A (1) ;
| if (! lox2 . begin (0 x29 ) ) {
// Serial . println (F(" Failed to boot second VL53L0X "));
| while (1)
| ; }
| // // initing LOX3
| TCA9548A (2) ;
| if (! lox3 . begin (0 x29 ) ) {
// Serial . println (F(" Failed to boot third VL53L0X "));
| while (1)
| ; }

// // initing LOX4
TCA9548A (3) ;
if (! lox4 . begin (0 x29 ) ) {
// Serial . println (F(" Failed to boot fourth VL53L0X ")); while (1)

;

}

}

71 | float sensor_1 () {
72 | TCA9548A (0) ;
73 | lox1 . rangingTest (& measure1 , false ) ;
74 | if ( measure1 . RangeStatus != 4) {
75 | sensor1 = measure1 . RangeMilliMeter ;
76 | } else {
77 | sensor1 = 4000;
78 | }
79 | return sensor1 ;
80 | }
81 | float sensor_2 () {
82 | TCA9548A (1) ;
83 | lox2 . rangingTest (& measure2 , false ) ;
84 | if ( measure2 . RangeStatus != 4) {
85 | sensor2 = measure2 . RangeMilliMeter ;
86 | } else {
87 | sensor2 = 4000;
88 | }
89 | return sensor2 ;
90 | }

91
92 | float sensor_3 () {
93 | TCA9548A (2) ;
94 | lox3 . rangingTest (& measure3 , false ) ;
95 | if ( measure3 . RangeStatus != 4) {
96 | sensor3 = measure3 . RangeMilliMeter ;
97 | } else {
98 | sensor3 = 4000;
99 | }
100 | return sensor3 ;
101 | }

102
103 | float sensor_4 () {
104 | TCA9548A (3) ;
105 | lox4 . rangingTest (& measure4 , false ) ;
106 | if ( measure4 . RangeStatus != 4) {
107 | sensor4 = measure4 . RangeMilliMeter ;
108 | } else {
109 | sensor4 = 4000;
110 | }
111 | return sensor4 ;
112 | }

Listing 15: Implementation of the distance measurement library

1 | # ifndef DISTANCE
2 | # define DISTANCE
3 | # include " distance .h"
4 | # include < Arduino .h >
5 | # include < Adafruit_VL53L0X .h >
6 | # include < Wire .h >

7
8 | void setID () ;
9 | float sensor_1 () ;
10 | float sensor_2 () ;

11 | float sensor_3 () ;
12 | float sensor_4 () ;

13
14 # endif

Listing 16: Header file for the distance measurement library

### 3.11 March 20, 2024

We implemented the above developed code on an Arduino Uno board to ensure its functionality. We attached the four Time-of-Flight (ToF) sensors to a dot board and connected their inputs using a multiplexer. We monitored the outputs through the serial monitor, confirming that the required angles were properly calculated.

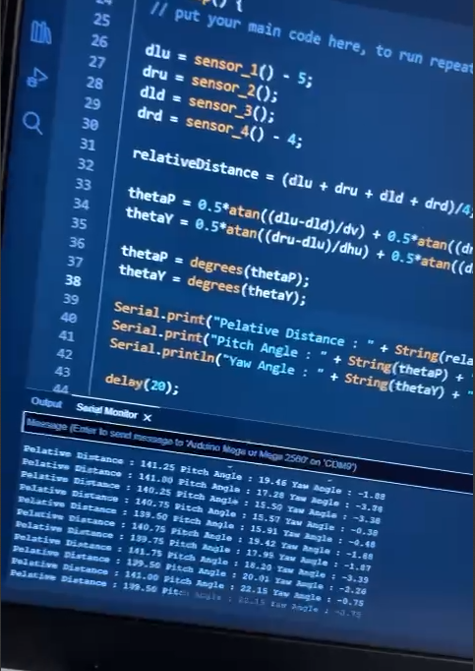
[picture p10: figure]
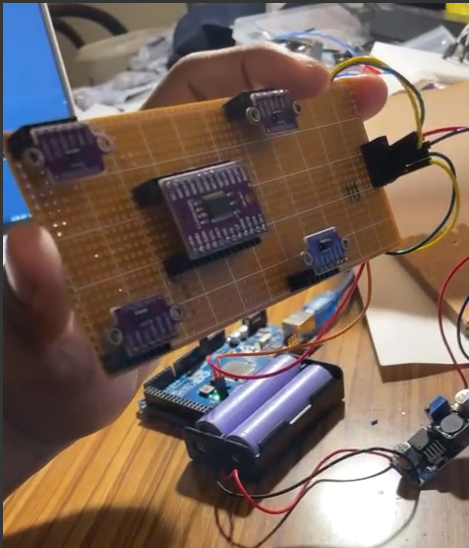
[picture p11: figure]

Figure 1: Serial Monitor Output | Figure 2: Sensor Arrangement

## Week 6 (Library Optimization)

### 3.12 March 24, 2024

During our testing phase with the VL53L0X distance sensor, we observed that the library provided for its use consumes over 50% of our available memory resources. This raised concerns about memory efficiency. To address this issue, we explored a more direct approach by programming the sensor using register-level interactions instead of relying on the library. By accessing the sensor’s hardware registers directly, we bypass the overhead associated with library functions, potentially leading to better memory utilization.

### 3.13 March 25, 2024

This method involves writing code that communicates directly with the sensor’s registers, enabling us to control its functionalities without the overhead of library functions. While this approach demands a deeper understanding of the sensor’s specifications and more meticulous coding, it offers the prospect of significantly reducing memory usage while maintaining desired functionality. Implementing this approach grants us finer control over the sensor’s operations and allows for tailored optimizations suited to our specific needs.

### 3.14 March 26, 2024

Aspect | Library Usage | Register Level Programming
Memory Usage | The library consumes over 50% of available memory resources, poten-tially limiting space for other func-tionalities. | Directly accessing memory regis-ters typically results in lower mem-ory usage compared to using high-level libraries. This can be advan-tageous in memory-constrained en-vironments.
Programming Complexity | Utilizing high-level libraries sim-plifies programming by abstracting away low-level details. Developers can use pre-defined functions and APIs, reducing complexity. | Programming with memory regis-ters requires a deep understand-ing of the microcontroller’s archi-tecture and the sensor’s specifica-tions. It involves precise manip-ulation of memory addresses and bit-level operations, making it more complex.
Control and Flexibility | While libraries offer convenience, they may limit control and cus-tomization options. Developers are often restricted to the functionali-ties and configurations provided by the library. | Interacting with memory registers provides granular control over the sensor’s functionalities. Develop-ers have the flexibility to customize code according to specific project requirements.
Performance | Performance may vary depending on the efficiency of the library im-plementation. While libraries gen-erally provide stable performance, they may introduce overhead due to abstraction layers. | Programming with memory regis-ters can result in optimized perfor-mance, as it allows for direct and ef-ficient communication with the sen-sor hardware.
Resource Efficiency | High-level libraries may consume additional resources, impacting both memory and processing efficiency. This can be a concern in resource-constrained embedded systems. | Leveraging memory registers can lead to efficient resource utilization, particularly in terms of memory and processing power.

Table 1: Comparison between Library Usage and Register Level Programming for VL53L0X Sensor

When prioritizing low complexity and easy debugging, high-level libraries often offer a more favorable solution:

1. Simplicity: High-level libraries abstract away low-level details, simplifying the development process. They provide pre-defined functions and APIs, which developers can easily integrate into their projects without needing an in-depth understanding of the underlying hardware architecture or sensor specifications.
2. Ease of Use: With high-level libraries, developers can focus on implementing the desired functionalities rather than worrying about low-level programming intricacies. This streamlined approach accelerates development and reduces the likelihood of errors or bugs introduced due to complex manual coding.
3. Debugging Support: High-level libraries are often well-documented and widely supported by the community. If issues arise during development or debugging, developers can rely on documentation, forums, and community resources to troubleshoot problems efficiently. Additionally, many libraries come with built-in error handling mechanisms, making it easier to identify and address issues.
4. Faster Iteration: High-level libraries enable rapid prototyping and iteration by providing ready-to-use functionalities. Developers can quickly test and iterate on their code without the need for extensive low-level debugging, resulting in shorter development cycles and faster time-to-market.

## Week 7 (Modbus Transmitter Development)

### 3.15 March 31, 2024

### Understanding Modbus and Its Importance

Modbus is a serial communication protocol designed for industrial use, created in 1979 by Modicon. It facilitates communication between electronic devices and is widely adopted due to its simplicity, reliability, and support for both serial (RS232, RS485) and TCP/IP communications. In industrial settings, Modbus is crucial for enabling different devices, such as sensors and controllers, to exchange information seamlessly. Its robust error-checking and standardized format ensure accurate and efficient data transmission, minimizing the risk of communication errors that could disrupt operations.

### 3.16 April 4, 2024

To implement Modbus in our project, we used the MAX485 TTL to RS485 Converter Module to convert TTL signals from sensors into RS485 signals suitable for long-distance communication. The ATmega2560 microcontroller’s TX and RX pins are connected to the DI and RO pins of the MAX485 module. The DE (Data Enable) and RE (Receive Enable) pins on the MAX485 are controlled by digital pins on the ATmega2560 to manage data flow direction. The RS485 output pins (A and
B) from the MAX485 module connect to the robot control panel’s RS485 input, ensuring accurate sensor data transmission.

### 3.17 April 5, 2024

To verify the Modbus setup, we used a USB to RS485 Communication Module to connect the RS485 bus to a PC. This setup allows for monitoring and debugging of data transmission. By connecting the USB side to the PC and the RS485 side to the RS485 bus, we use terminal software or Modbus Poll to inspect the data flow. Modbus Poll, a Modbus master simulator, helps send queries and visualize responses from the RS485 bus devices. This ensures the integrity and accuracy of data before final integration with the robot control panel, enabling real-time monitoring and prompt issue resolution.

## Week 8 (Component Selection)

### 3.18 April 7, 2024

The components were selected based on their functionality, compatibility, market availability, feasibility, robustness, ease of soldering, and cost-effectiveness. Alternative options were considered to ensure optimal performance and cost-effectiveness.

### Microcontroller

- Selected Component: ATMEGA2560-16AU
- Description: 8-bit AVR Microcontroller, 4.5-5.5V, 16MHz, 256KB Flash, 4KB EEPROM, 8KB SRAM, 86 GPIO pins, 100-pin TQFP, Industrial Grade (-40°C to 85°C), Pb-Free
- Purpose: Main processing unit for data handling and communication.
- Reason for Selection: High GPIO count, ample memory, industrial grade suitable for robust applications.
- Market Availability: Widely available.
- Feasibility: High, commonly used microcontroller.
- Cost-Effectiveness: Economical and reliable.
- Alternative Considered: PIC18F46K22 not selected due to lower GPIO count and smaller memory capacity.

### 3.19 April 9, 2024

### Distance Measurement Sensor

- Selected Component: VL53L0X
- Description: Time-of-Flight (ToF) Laser Rangefinder Module
- Purpose: Provides accurate distance measurements for applications requiring precise ranging and object detection.
- Reason for Selection:The VL53L0X offers high-precision distance measurement capabilities with a range of up to 2 meters. It is compact and easy to integrate into various projects, making it ideal for applications such as robotics, drones, and proximity sensing. The sensor’s ability to operate in a wide range of lighting conditions and its immunity to ambient light interference enhance its reliability and performance.
- Market Availability: Widely available from major suppliers such as Digi-Key, Mouser, and other electronic component distributors.
- Feasibility: High, due to its common use in various applications and extensive documentation and support available from the manufacturer.
- Cost-Effectiveness: Cost-effective compared to similar sensors, offering a good balance between performance and price. Its widespread availability also contributes to its cost-effectiveness.
- Alternative Considered: VL6180X

### Multiplexer

- Selected Component: PCA9546ADG4
- Description: 4-Channel I2C and SMBus Multiplexer with Reset Functions, 2.3 to 5.5V, -40 to 85°C, 16-pin SOIC (D), Green (RoHS no Sb/Br)
- Purpose: Multiplexing I2C signals from multiple TOF sensors to the microcontroller.

- Reason for Selection: Efficient channel management, compact SOIC package.
- Market Availability: Widely available.
- Feasibility: High, commonly used in I2C applications.
- Cost-Effectiveness: Economical and reliable.
- Alternative Considered: VL6180X
- Reason for Not Selecting:The VL6180X has a shorter range and is more suited for proximity sensing and ambient light measurement rather than precise long-distance ranging, making the VL53L0X a better fit for applications requiring accurate distance measurements.

### 3.20 April 11, 2024

### Crystal Oscillator

- Selected Component: ABLS2-16.000MHZ-D4Y-T
- Description: HC/49US (AT49) Low Profile Surface Mount Microprocessor Crystal
- Purpose: Provides clock signal for the microcontroller.
- Reason for Selection: Reliable frequency stability, compact package.
- Market Availability: Easily available.
- Feasibility: High, standard component for microcontroller applications.
- Cost-Effectiveness: Economical and reliable.

### USB Connector

- Selected Component: USBA1HSW6
- Description: USB-A (USB TYPE-A) Receptacle Connector, 4 Position
- Purpose: USB connectivity for data transfer or power supply.
- Reason for Selection: Standard USB-A receptacle with through-hole mounting.
- Market Availability: Readily available.
- Feasibility: High, standard component.
- Cost-Effectiveness: Economical and reliable.

### 3.21 April 12, 2024

### Resistors

- Selected Component: RC0805JR-070RL
- Description: Chip Resistor Ohm, Jumper, ±5%, 0.125W, 0805 (2012 Metric), RoHS, Tape and Reel
- Purpose: Jumper resistors for circuit configuration.

- Reason for Selection: Standard 0805 size for easy placement and soldering.
- Market Availability: Widely available.
- Feasibility: High, due to standard use.
- Cost-Effectiveness: Economical and reliable.

Headers

- Selected Component: M22-5320305R
- Description: Header, 3-Pin, Dual row
- Purpose: Connection interface for external components or programming.
- Reason for Selection: Standard dual-row header for reliable connections.
- Market Availability: Commonly available.
- Feasibility: High, standard component with broad availability.
- Cost-Effectiveness: Economical and reliable.

### Capacitors

- Selected Component: C1206C104K2RACTU
- Description: CAP CER 0.1UF/0.3UF 200V 10% X7R 1206
- Purpose: General-purpose decoupling and filtering for stable power supply to various components.
- Reason for Selection: X7R dielectric provides stable capacitance; 1206 footprint suits compact PCBs.
- Market Availability: Widely available from major suppliers.
- Feasibility: High due to common use.
- Cost-Effectiveness: Balanced performance and price.
- Alternative Considered: GRM31CR61A106KE15L not suitable due to different dielectric material.

### LED

- Selected Component: CMP-1488-00009-1
- Description: Typical RED GaAs LED
- Purpose: Status indication.
- Reason for Selection: Reliable, widely used, good visibility, low power consumption.
- Market Availability: Readily available.
- Feasibility: High in various applications.
- Cost-Effectiveness: Economical and reliable.

## Week 9 (Schematic and PCB Design)

### 3.22 April 15, 2024

Today marks the beginning of the schematic design phase for our PCB project. Following careful component selection to meet project requirements, our team has commenced the schematic layout process.

- Translating component specifications into circuit diagrams.
- Ensuring compatibility and functionality through detailed design review.

The next steps involve thorough validation and verification of the schematic before proceeding to PCB layout. Coordination among team members remains crucial to ensure alignment with project timelines and goals.

### 3.23 April 17, 2024

After thorough validation and verification of the schematic, we have begun the process of placing components on the PCB. Our primary focus is to maintain the minimum size of the PCB while ensuring optimal layout for functionality and manufacturability.

- Started placing components strategically to optimize space utilization.
- Ensured adherence to design constraints and specifications during placement.
- Implemented initial routing considerations to minimize signal interference and achieve efficient signal paths.

Two days into component placement, we transitioned to routing using JL PCB rules to further refine the layout:

- Applied JL PCB rules for routing to ensure signal integrity and minimize noise.
- Continued to prioritize compactness while maintaining clear separation between high-speed and low-speed signals.
- Iteratively reviewed and adjusted routing paths to optimize performance and reliability.

The next phase involves comprehensive review and validation of the routed design before finalizing for production.

### 3.24 April 20, 2024

Today, we completed the finalization and validation of the PCB design. Following the meticulous routing according to JL PCB rules, we have successfully generated Gerber files and NC drill files required for manufacturing.

- Conducted a detailed review and validation of the routed PCB design to ensure it meets all specifications and functional requirements.
- Verified signal integrity, power distribution, and thermal management aspects of the design.
- Prepared comprehensive documentation, including assembly drawings and manufacturing notes, to support smooth production.

The finalized design is now ready for manufacturing in China. The Gerber files and NC drill files have been carefully checked and packaged for transmission to our manufacturing partner.

## Week 10 (Enclosure Design)

### 3.25 April 22, 2024

Today, we created a SolidWorks design for a simple box-like enclosure to incorporate all the TOF sensors, aimed at demonstrating our concept. Initially, we considered building a vacuum gripper, but due to feasibility issues, we focused on the enclosure. After exploring various conceptual designs, we selected a feasible option and modeled it in SolidWorks. However, the design required the TOF sensors to be spaced 10cm apart, resulting in excessive use of material and space. This issue needs to be addressed in future iterations to optimize the design.

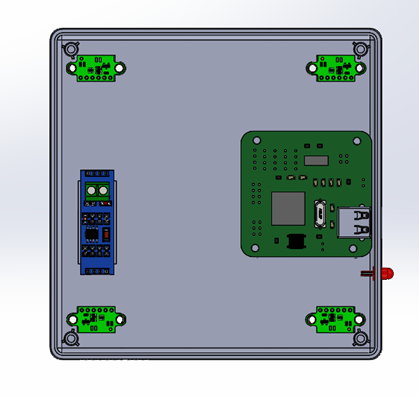
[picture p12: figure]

### 3.26 April 26, 2024

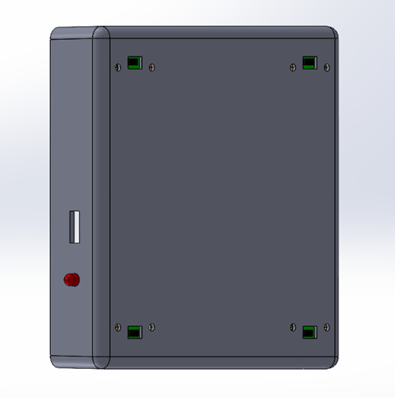
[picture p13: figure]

As the project advanced, we discussed the possibility of creating an adjustable enclosure. The aim is to provide users with the flexibility to modify the product components based on the dimensions of different vacuum grippers. This new design would allow the four TOF sensors to be re positioned as needed and would include a box housing the PCB, which could be attached to the gripper. Our objective is to ensure compatibility with a wide range of vacuum grippers without compromising on performance or increasing the overall size. This adjustable enclosure concept is intended to enhance the versatility and user-friendliness of our product, making it adaptable to various applications and user requirements.

## Week 11 (Enclosure Design)

### 3.27 April 28, 2024

Today, we extensively discussed the challenges encountered while developing the adjustable enclosure for our project:

- Variability in Gripper Sizes: The significant size differences among vacuum grippers necessitated a highly adaptable sensor arrangement.
- Attachment Reliability: Finding a universal attachment method that could accommodate the diverse designs of grippers proved challenging.
- Sensor Mobility: Design complexity increased due to the requirement for TOF sensors to move in two directions.

- Mechanical Durability: Ensuring the mechanical strength and stability of the adjustable components posed significant challenges.

These challenges prompted us to reassess our approach. We concluded that focusing on a specific vacuum gripper model would enable us to devise a more robust and efficient design, ensuring optimal performance in our product.

### 3.28 April 30, 2024

Today’s efforts were focused on several critical tasks aimed at advancing our project:
We began by designing a sample vacuum gripper that incorporates designated mounting spots specifically tailored for the TOF sensors. This meticulous approach ensures that the sensors maintain an unobstructed line of sight, thereby preserving the gripper’s functionality and enhancing overall performance.
In parallel, we leveraged and enhanced an existing gripper model from this link to meet our precise project requirements. This model provided a solid foundation that we modified to seamlessly integrate with our sensor arrangement and operational needs.
Additionally, we developed a separate enclosure designed specifically for the PCB. This enclosure features a strategically placed USB port that facilitates convenient data retrieval directly from the PCB. Inside this enclosure, the TOF sensors connect directly to the PCB, ensuring streamlined functionality. The entire assembly can be securely attached to the gripper using nuts, which guarantees stability during operation.
These integrated advancements represent a significant stride towards achieving our project goals. They ensure that our sensor technology operates effectively within the context of the vacuum gripper’s functionality, paving the way for robust and reliable performance in practical applications.

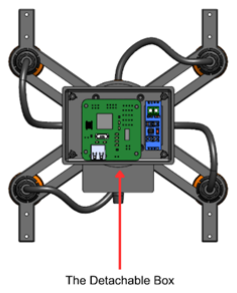
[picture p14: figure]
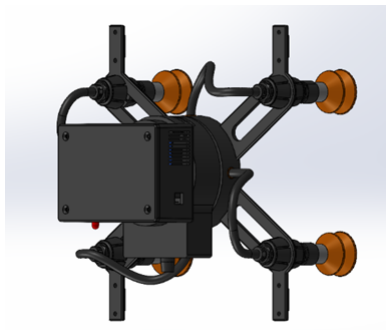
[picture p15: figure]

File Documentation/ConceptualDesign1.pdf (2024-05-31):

# UNIVERSITY OF MORATUWA, SRI LANKA

## Department of Electronic and Telecommunication Engineering

# EN2160 - Electronic Design Realization

## Conceptual Design Report

## FM Radio

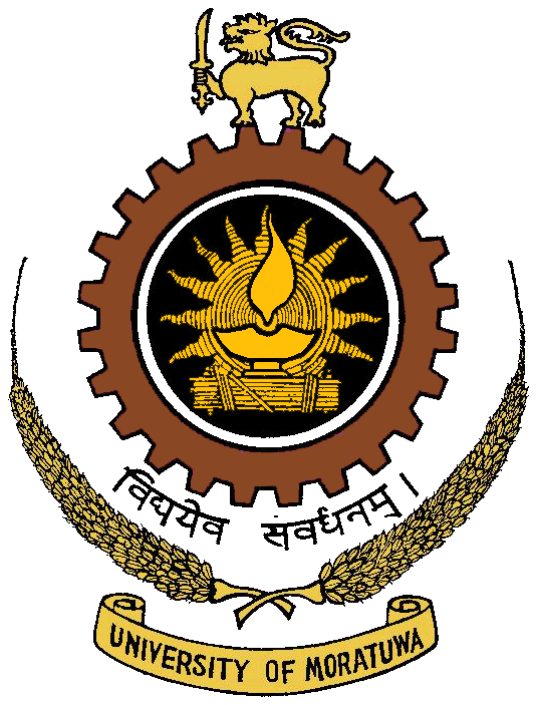
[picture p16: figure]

## SAMARAWEERA D T

200564J

### 7 June 2023

## Content

## Conceptual designs and Functional block diagrams

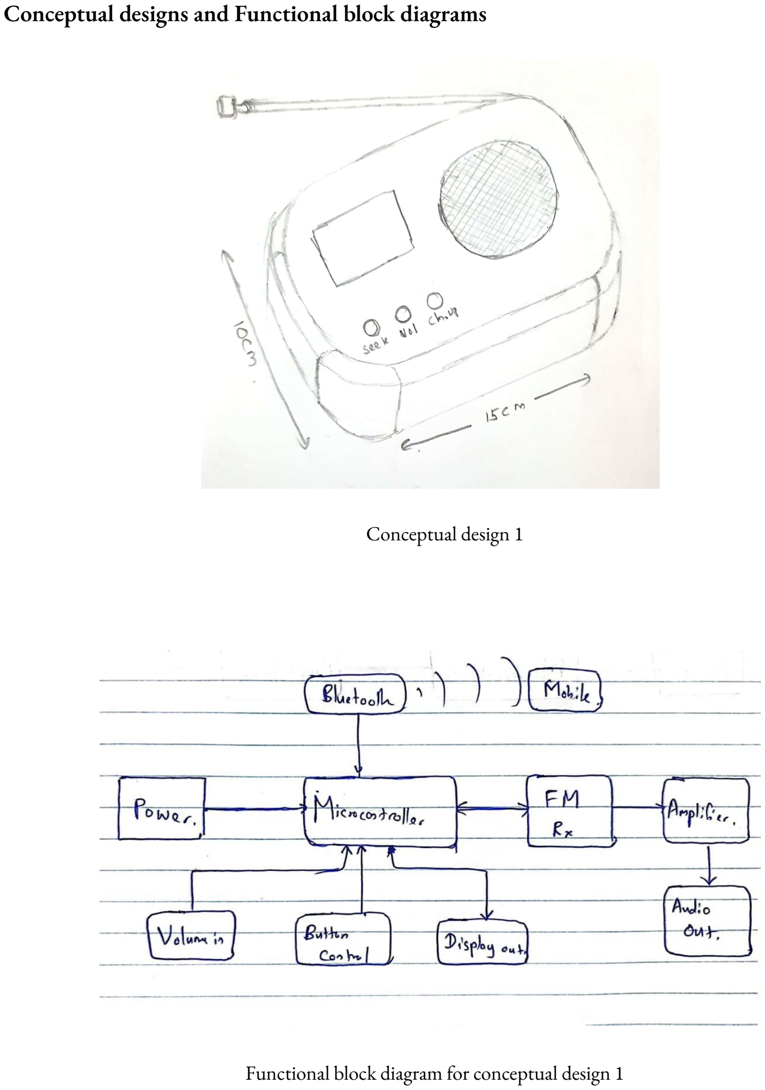
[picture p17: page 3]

### Conceptual design 1

### Functional block diagram for conceptual design 1

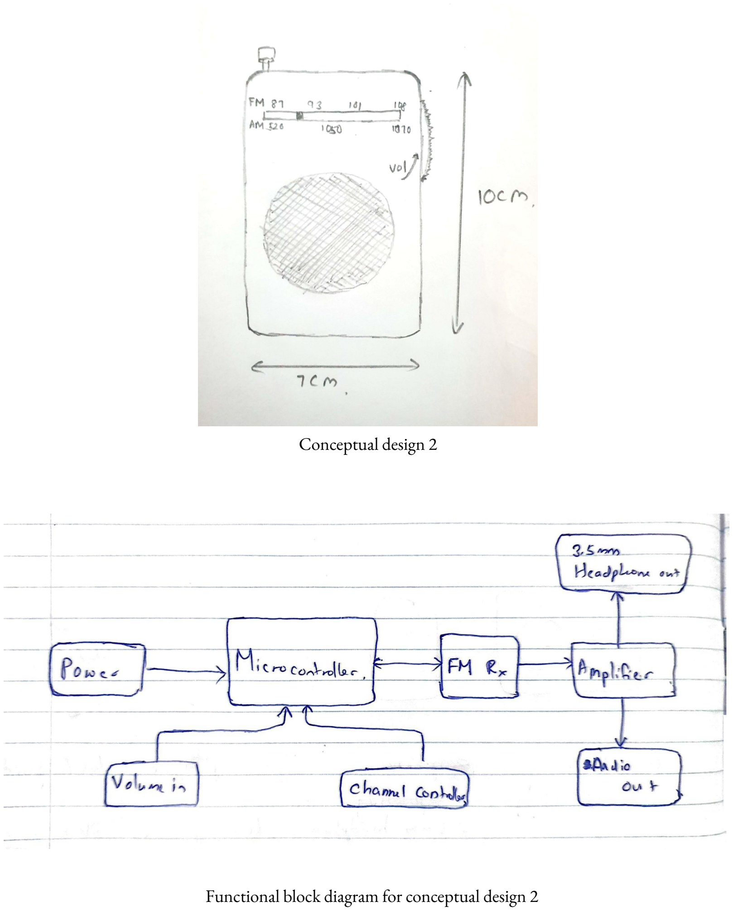
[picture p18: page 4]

### Conceptual design 2

### Functional block diagram for conceptual design 2

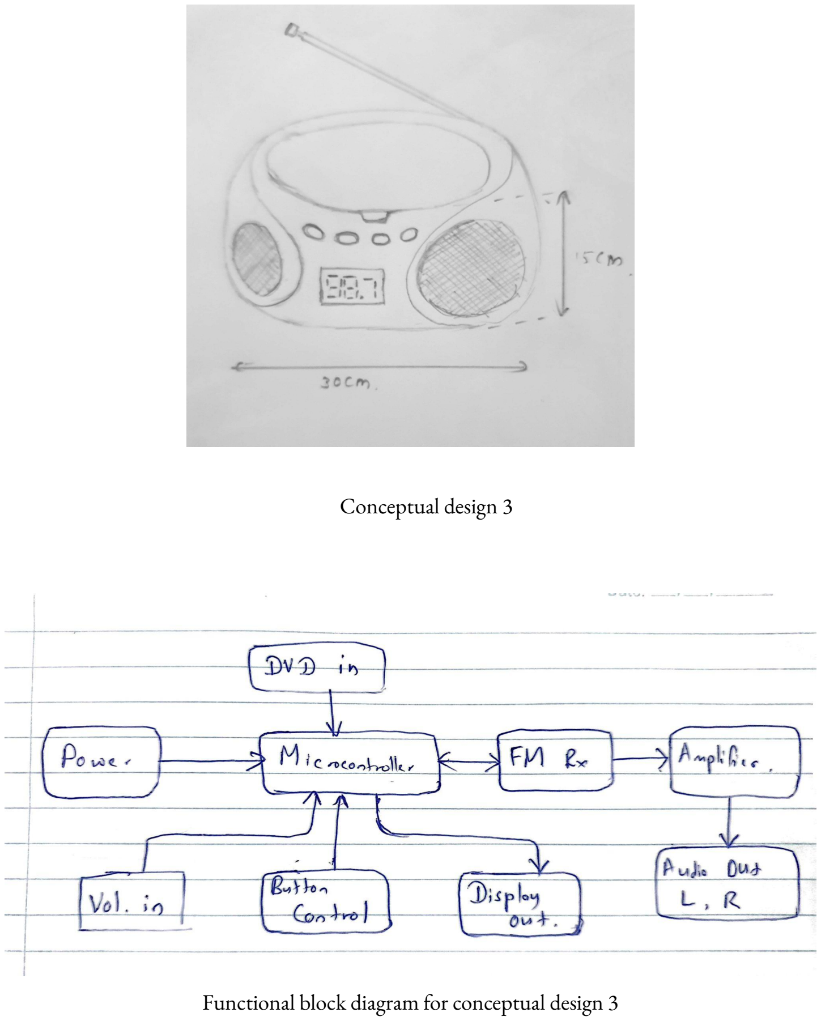
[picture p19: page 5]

### Conceptual design 3

### Functional block diagram for conceptual design 3

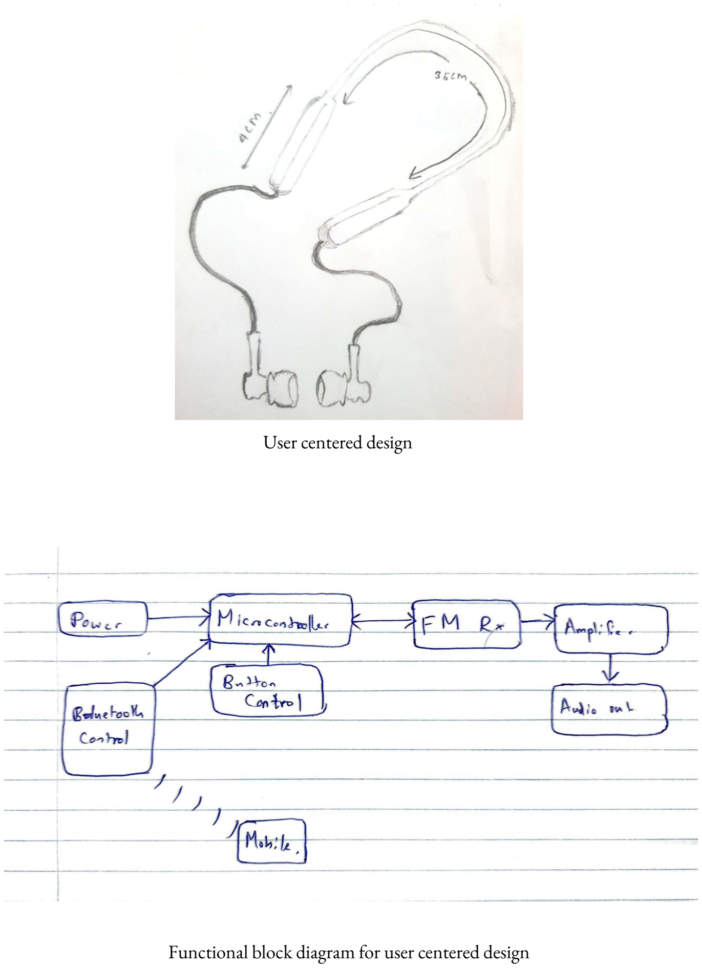
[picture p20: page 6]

### User centered design

### Functional block diagram for user centered design

## Complete Comparison

| Conceptual design 1 | Conceptual design 2 | Conceptual design 3 | User centered design
Newly added features | Bluetooth capability Digital display out Can be used as a power bank | 3.5mm headphone out Portability | DVD player Stereo speakers Digital display out | 100% portable Stereo earbuds Bluetooth
Removed features | Stereo speakers Earphone support | Digital display Bluetooth | Earphone support | Digital display
Enclosure design criteria comparison | Functionality | 8 | 7 | 8 | 6
| Aesthetics | 9 | 7 | 9 | 9
| Heat dissipation | 9 | 8 | 9 | 6
| Assembly and serviceability | 8 | 7 | 8 | 6
| Ergonomics | 8 | 9 | 9 | 9
| Simplicity | 9 | 7 | 7 | 6
| Durability | 9 | 8 | 9 | 8
Functional block design criteria comparison | Functionality | 8 | 7 | 8 | 6
| User experience | 7 | 8 | 9 | 9
| Manufacturing feasibility | 9 | 7 | 7 | 6
| Cost | 8 | 8 | 7 | 7
| Performance | 7 | 7 | 8 | 7
| Future proofing | 7 | 8 | 8 | 9
| Power | 7 | 8 | 6 | 9
Total | | 113 | 106 | 112 | 103

## Evaluation Criteria

Enclosure Design Criteria:

1. Functionality: How well the design supports the main functionalities? 2. Aesthetics: How much eye catching and overall appeal of the user? 3. Heat dissipation: How much heat is generated and how well it has been managed? 4. Assembly and serviceability: How easily does the assembly and disassembly is done?

5. Ergonomics: How well does the design fit in the user's hand and allow easy interaction?

## 6. Durability: How well does the design withstand impacts and environmental conditions? 7. Simplicity

Functional block diagram criteria:

1. Functionality: How well the circuit design meets functional requirements? 2. User experience: How intuitive and user-friendly is the interaction? 3. Manufacturing feasibility: Evaluate the feasibility of manufacturing the design 4. Cost: Evaluate the overall cost effectiveness for the provided functionality 5. Performance:Evaluate signal quality, resolution and bandwidth range?

6. Future proofing: To what extent does the design allow for easy replacement or upgrade of

## individual components? 7. Power Efficiency: How effectively does the device manage power consumption?

## List of names who contributed to Design Driven Innovation

### 200709K Wikramanayaka R.S.D 200564J Samaraweera D.T 200693D Wanigathunga W.A.S.S 200023C Amarasekara A.T.P 200722T Wijerathna K.D

200312L Kowrisaan S.
200398D Mithushan K.
200725F Wijesekara W.M.E.P.B.B.

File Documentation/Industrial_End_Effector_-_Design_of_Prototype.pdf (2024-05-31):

## UNIVERSITY OF MORATUWA, SRI LANKA

## Faculty of Engineering

Department of Electronic and Telecommunication Engineering Semester 4 (Intake 2021)

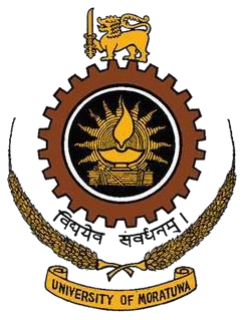
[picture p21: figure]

# Industrial End Effector

## Prototype Design

This report is submitted as a partial fulfillment for the module EN2160 - Electronic Design Realization, Department of Electronic and Telecommunication Engineering, University of Moratuwa.

Kodikara U.S.S.
Gunewardane E.R.N.H
Sehara G.M.M.
Kodithuwakku J.N.

(210293K)
(210200C)
(210583B)
(210294N)

## 1. User Requirements

An accurate and efficient end effector plays a critical role in reliably and efficiently completing precise tasks by acting as the interface between a robotic system and its operating environment. The end effector is the "hand" of the robot, used in space exploration, medical robotics, and industrial automation. It oversees handling things, carrying out delicate tasks, and carrying out difficult maneuvers. While its effectiveness ensures optimal performance, minimizes errors, and maximizes production, its accuracy guarantees activities are done with the necessary level of precision. An accurate and efficient end effector is critical to many aspects of robotics and automation, including manufacturing lines, supermarket logistics and surgery, as it directly affects the efficiency, speed, and safety of operations.

This industrial end effector project which was proposed by Professor Jayasinghe aims to create a game-changing device for automating tasks in places like supermarkets and factories. Unlike traditional vacuum-based methods, this new device can figure out how an object is oriented before a robot arm touches it. This means the robot arm can work more efficiently and safely. For example, in a supermarket, it could help sort products faster. In a factory, it could help assemble things more accurately. Overall, it makes automation smarter and more reliable, improving efficiency and reducing errors in various industries.

The following are some user requirements of an accurate end effector.
- Cost effectiveness: The end effector should be affordable to purchase and operate, minimizing the need for expensive maintenance or consumables.
- Time effectiveness: It should complete tasks quickly, without sacrificing accuracy, ensuring efficient operation within short timeframes.

- User-friendly interface: Operating the end effector should be simple and intuitive, requiring minimal training or technical expertise.
- Size and durability: It should be compact yet sturdy, capable of withstanding harsh conditions without compromising performance.
- Real-time data monitoring: Users should receive immediate feedback on its operations, enabling timely adjustments and monitoring of performance.

## 2. Conceptual Designs

The following five conceptual designs were developed by the group members after having several brainstorming sessions and discussions within the group.

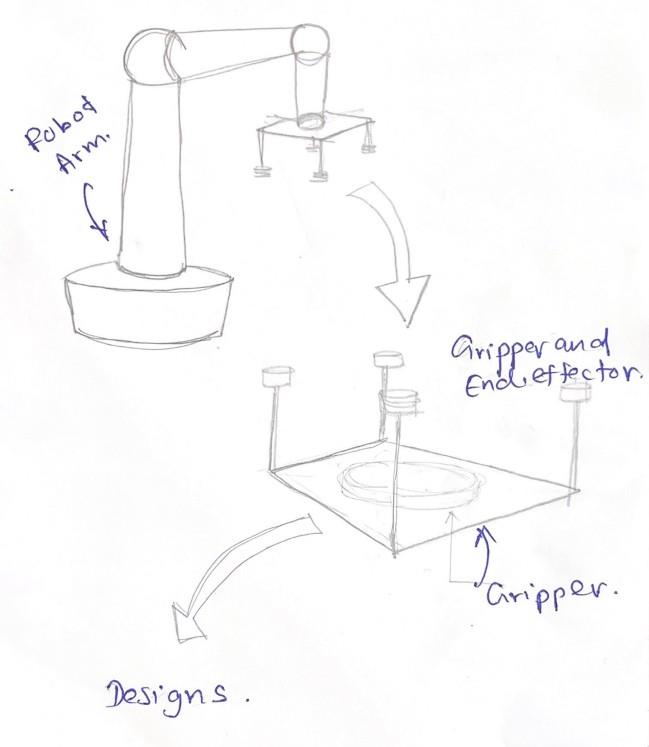
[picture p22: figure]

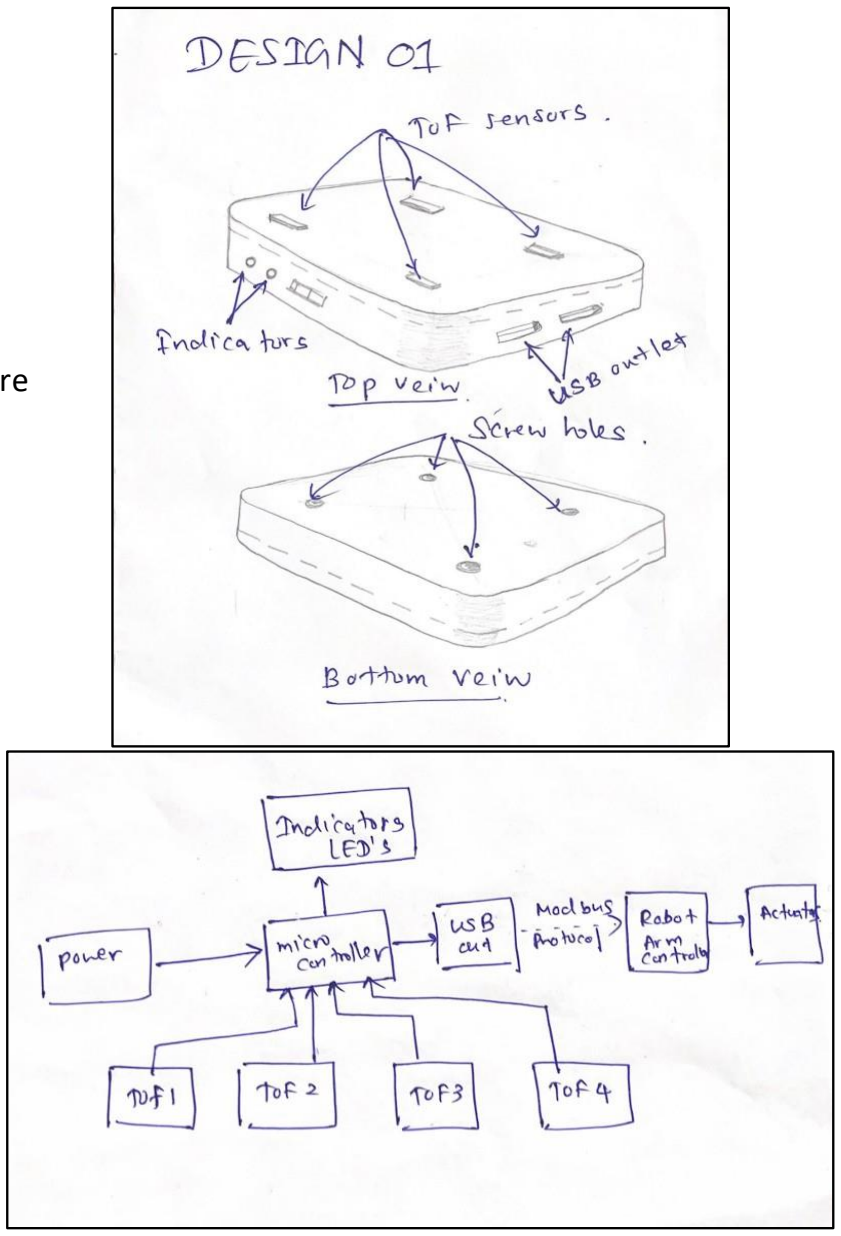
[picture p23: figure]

Enclosure

This will be the main structure of the robot arm that we are going to use for the end effector. The following designs will be mounted to this arm. The data that is received by the end effector will be fed to the robot arm. Then the arm controller will be able to take decisions according to the data fed to it.

## 2.1 Design 1

In this design we use the Time-of-Flight concept. We use 4 vl53l0x sensors here to measure distances. Modbus protocol is used to communicate with the robot arm controller though USB.

Functional Block Diagram

## 2.2 Design 2

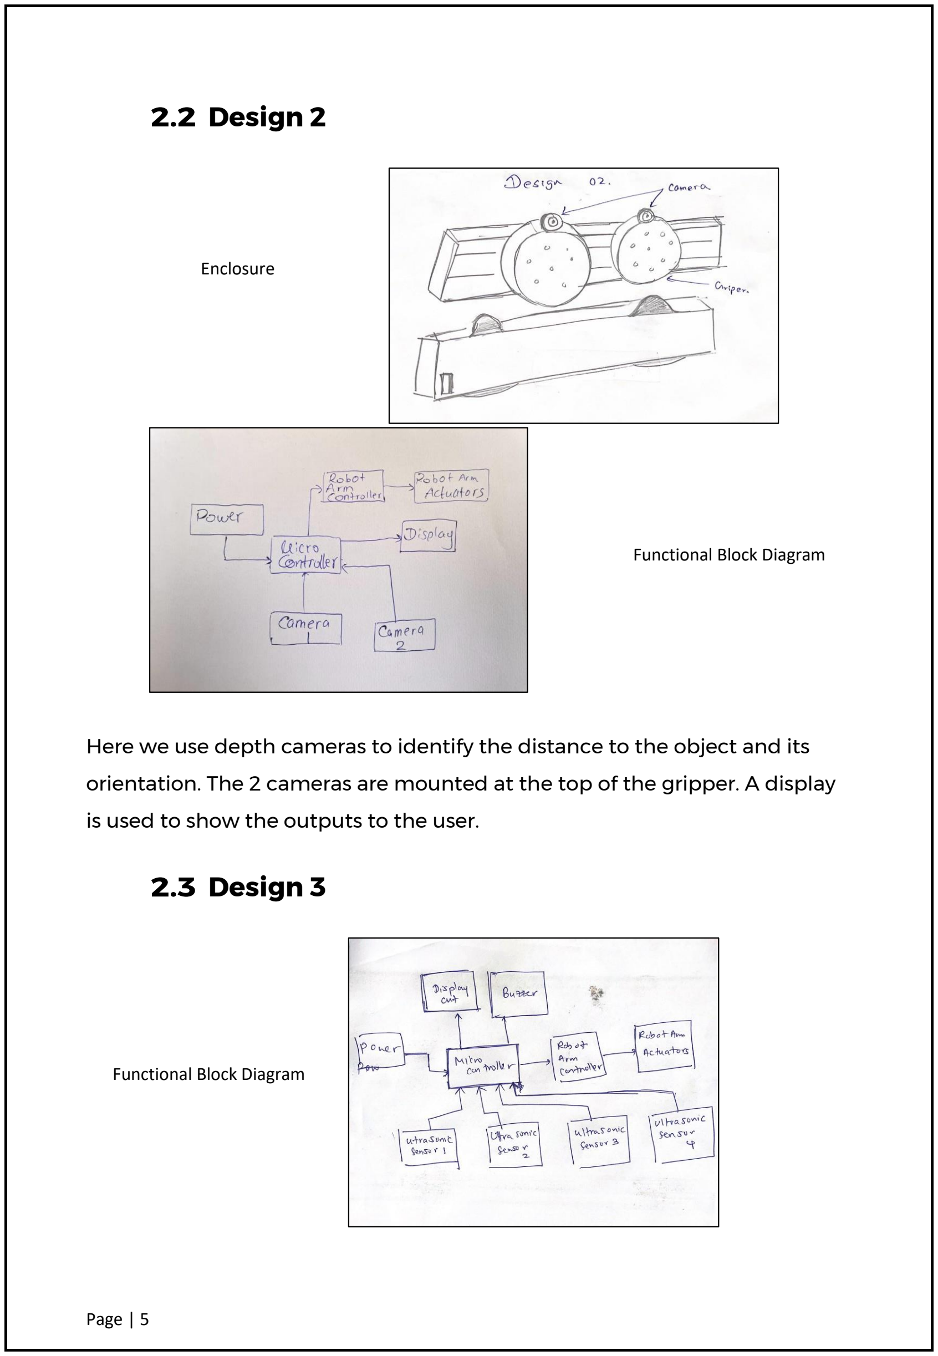
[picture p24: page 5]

Here we use depth cameras to identify the distance to the object and its orientation. The 2 cameras are mounted at the top of the gripper. A display is used to show the outputs to the user.

## 2.3 Design 3

Enclosure

Functional Block Diagram

Functional Block Diagram


Here we use an ultrasonic sensor to map the distances to the object. From the distances measured we thought of identifying the orientations of the object. This design also has a display, and it has a buzzer.

## 2.4 Design 4

Enclosure


Enclosure | Functional Block Diagram

We use the Kinect here to measure the distances and to map the orientation of the object. Like the depth cameras design, the Kinect is also mounted above the gripper. A major drawback of this design is the cost of the Kinect sensor.

## 2.5 Design 5

Enclosure

In this design we thought of using a mechanical approach to measure the distances. We use 4 mechanical probes with encoders attached to them. The output of the encoders is fed to the micro controller and then the processed data to the robot arm actuators.

Functional Block Diagram

## 3. Evaluation of the Designs

| Design 1 | Design 2 | Design 3 | Design 4 | Design 5
Newly added features | Indicator LEDs USB Outputs RS 485 Module RS485 USB Converter | Display output. 2 Cameras | Display Output Buzzer output Ultrasonic Sensors | Kinect Sensor Display Output | Mechanical Probes Encoders USB Output
Removed features | Buzzer Output Display Output | LED Indicators Modbus Protocol | USB Outputs | USB Outputs Buzzer | Display Output
| | Design 1 | Design 2 | Design 3 | Design 4 | Design 5
Enclosure design criteria comparison | Functionality | 9 | 9 | 8 | 8 | 7
| Aesthetics | 7 | 8 | 7 | 8 | 6
| Heat dissipation | 7 | 9 | 7 | 8 | 9
| Assembly and serviceability | 8 | 7 | 8 | 6 | 8
| Ergonomics | 8 | 8 | 7 | 8 | 7
| Simplicity | 9 | 7 | 9 | 7 | 8
| Durability | 9 | 7 | 8 | 8 | 7
Functional block design criteria comparison | Functionality | 9 | 9 | 8 | 9 | 6
| User experience | 8 | 9 | 7 | 9 | 6
| Manufacturing feasibility | 9 | 7 | 9 | 7 | 8
| Cost | 8 | 6 | 9 | 4 | 8
| Performance | 9 | 8 | 7 | 9 | 6
| Future prolongs | 8 | 9 | 7 | 9 | 6
| Power | 8 | 7 | 8 | 7 | 7
Total | | 118 | 108 | 117 | 117 | 107

## 3.1 Enclosure design criteria

- Functionality: How well-supported are the primary functionalities by the design?
- Aesthetics: To what extent is the user visually appealing overall?
- Heat dissipation: How much heat is produced and how effectively is it controlled?
- Assembly and serviceability: To what extent is it easy to assemble and disassemble?
- Ergonomics: How easily can the user engage with the design and how well does it fit in their hand?
- Simplicity.

## 3.2 Functional block diagram criteria

- Functionality: To what extent do functional needs get met by the circuit design?
- User experience: To what extent is the interaction intuitive and user-friendly?
- Manufacturing feasibility: Determine whether the design can be manufactured.
- Cost: Analyze the total cost-effectiveness of the capability offered.
- Performance: Assess the bandwidth range, resolution, and signal quality.
- Future proofing: How easily can individual components be upgraded or replaced in the design?
- Power Efficiency: To what extent is the device’s power usage managed effectively.

## 4. Design Selection

According to the evaluation criteria, the first design has been chosen to develop.

### 4.1 Features of the Design

The choice of Conceptual Design 01 was a strategic decision, primarily due to its combination of compact size and durable construction. This compact and easily mountable design ensures seamless integration into the robot arm with vacuum gripper, optimizing space utilization.

Furthermore, the integration of Time-of-Flight (ToF) sensors within Conceptual Design 01 offers a significant advantage by providing more accurate and reliable measurements. Maintaining a sufficient distance between ToF sensors ensures that the percentage error remains below 1%, guaranteeing precise results and enhancing the overall accuracy of our system.

The inclusion of a USB port facilitates both power input to the circuit and communication with the robot, streamlining the setup process and enhancing connectivity.

In addition, the deliberate choice to utilize only essential indicator LEDs while removing buzzers and displays enhances the industry suitability of Conceptual Design 01. By prioritizing simplicity and functionality, we ensure that our solution meets industry standards and requirements without unnecessary distractions or complexities.

## 5. SolidWorks design


## 6. Schematic and PCB design

Title; Multiplexer_SCL; Multiplexer_SDA; Designator; MCU.SchDoc; Multiplexer_SCL TOF_1C; TOF_1D; TOF_2C; TOF_2D; TOF_3C; TOF_3D; TOF_4C; TOF_4D; Multiplexer.SchDoc; Header 4; GND; VBUS; USB-A1HSW6; Header 4X2; 01 None; PIP301; PIP302; PIP303; PIP304; COP3; PIP401; PIP402; PIP403; PIP404; COP4; PIP501; PIP502; PIP503; PIP504; COP5; PIP601; PIP602; PIP603; PIP604; COP6; PIP701 PIP702; PIP703 PIP704; PIP705 PIP706; PIP707 PIP708; COP7; PIP801; PIP802; PIP803; PIP804; COP8; PIP708; PIP706; NLD0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

File: C:\Users\..\Main.SchDoc Drawn By:

Date: 4/02/2024 Sheet of

Number Revision Size

End effector- Main

Power Supply.SchDoc


File: C:\Users\..\MCU.SchDoc Drawn By:

Main Controller Unit (Atmega 2560)

Title; RESET 3; GND 8; SCL 14 SDA 15; VCC 16; PCA9546ADG4; GND; Multiplexer Circuit; Multiplexer_SDA; Multiplexer_SCL TOF_1C; TOF_1D; TOF_2C; TOF_2D; TOF_3C; TOF_3D; TOF_4C; TOF_4D; None; GND Pins

closer to the VCC ,

Coupling cap must

File: C:\Users\..\Multiplexer.SchDoc Drawn By:

Date: 4/02/2024 Sheet of

Number Revision Size


File: C:\Users\..\Power Supply.SchDoc Drawn By:


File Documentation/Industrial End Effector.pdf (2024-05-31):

# Review Progress, Plan Next Steps, Create Stakeholder Map & Observe Users

## EN2160 - Electronic Design Realization


## Industrial End Effector

Gunawardane E. R. N. H. 210200C Kodikara U.S.S. 210293K
Kodithuwakku J. N. 210294N Sehara G. M. M. 210583B

Introduction
In fast-paced industrial automation, a new end effector equipped with four Time-of-Flight (ToF) sensors is designed to enhance accuracy and efficiency. Unlike conventional grippers, this innovative tool detects box orientation in real-time, allowing the robot to adjust its grip instantly for a secure hold, regardless of how the box is positioned. This advancement minimizes errors and delays, reducing production downtime and damage, while also accommodating various box shapes and sizes without manual adjustments. By streamlining workflows and decreasing product damage, this smart end effector not only improves operational efficiency but also delivers cost savings, making industrial robotics more reliable and adaptable.

Review Progress

From the selection of the project, we have considered several ideas such as using LiDAR sensors, machine vision techniques, and Time-of-Flight (ToF) sensors. After reviewing various videos and research papers, we have concluded that utilizing ToF sensors is the most effective approach. Subsequently, we have opted to detect the orientation of the box using four ToF sensors and transmit this information to the robot control panel. To achieve this, we will employ the Modbus protocol and provide the feed through a USB output. Currently, we are sketching the basic design of ToF sensor placements and studying the Modbus protocol.

Plan Next Steps

Our next steps involve conducting laboratory testing with four ToF sensors attached to a panel and boxes with different orientations. We will measure distances using these sensors and adjust the orientation accordingly. Subsequently, we plan to plot a graph of the orientation in degrees relative to each ToF sensor reading and establish the mathematical relationship between them. This is our immediate focus. Following this, we intend to convert the data into a format relevant to the robot control panel using coordinates. For this task, we will utilize the Modbus protocol.

Create Stakeholder Map

As an undergraduate group working on the project, the primary stakeholders include the project team of us, who are responsible for design, testing, and implementation. The University of Moratuwa, supervising the project, plays a crucial role in providing guidance and resources, ensuring academic standards are met. Industrial clients, which could be simulated or hypothetical, represent the end-users of the end effector, highlighting the importance of meeting industry needs and aligning with real-world applications. Suppliers of components and materials provide essential resources for building the end effector, contributing to the project's success and functionality. Additionally, classmates may serve as collaborators or provide valuable feedback during various stages of the project, fostering collaboration and knowledge exchange within the academic community. Finally, the academic community benefits from potential contributions to research, enriching the learning experience and advancing understanding in the field of industrial automation.


Observe Users

We have found some similar projects related to this, and below, we have listed them.
ABB Robotics - Palletizing Cartons (youtube.com) (https://www.youtube.com/watch?v=7U1-X5ogsKA)
ABB Robotics - Palletizing drums of paint (youtube.com) (https://www.youtube.com/watch?v=ZT5KFt3muwo)
Palletizing Robot Handling a Variety of Boxes (youtube.com) (https://www.youtube.com/watch?v=ZkbAPeItvgE)

Conclusion

In conclusion, our end effector project involves a diverse set of stakeholders, each with unique needs and expectations. From the project team responsible for its development to the University of Moratuwa providing guidance, and potential industrial clients seeking practical solutions, addressing the requirements of each stakeholder group is crucial for the success of our endeavor. By carefully considering and catering to the needs of these stakeholders, we can ensure the successful marketing and adoption of our end effector in the industrial automation sector.

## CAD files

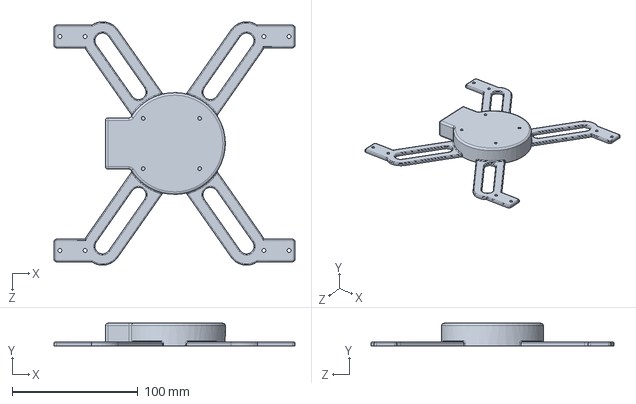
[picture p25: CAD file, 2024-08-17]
Enclosure Design/Demo/New new gripper new.SLDPRT
191.9 x 18.0 x 193.8 mm

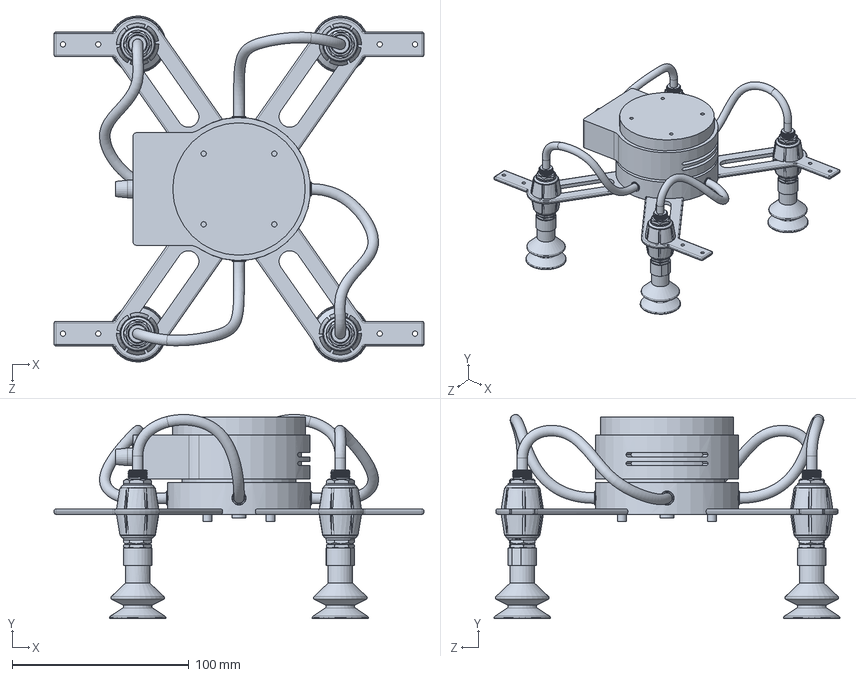
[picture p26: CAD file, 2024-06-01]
Enclosure Design/Vacuum gripper.SLDPRT
209.3 x 115.5 x 195.8 mm

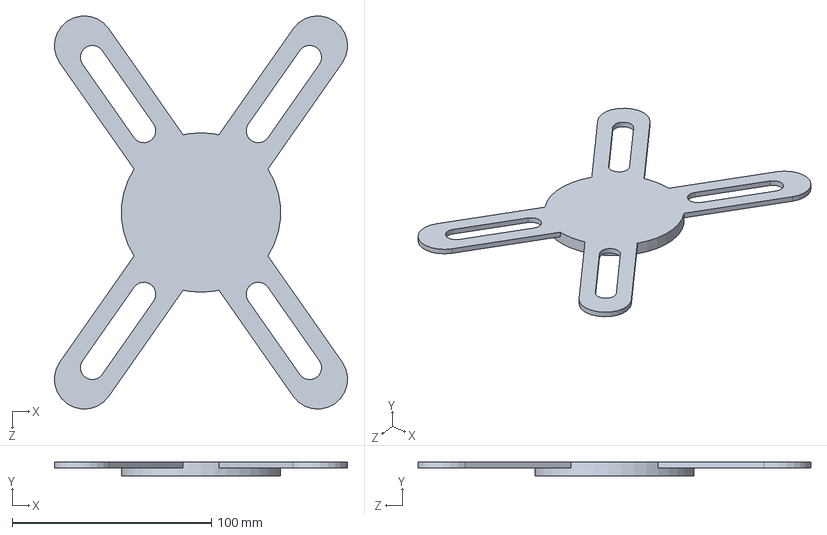
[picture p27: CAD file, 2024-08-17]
Enclosure Design/Demo/Part1.SLDPRT
147.0 x 7.00 x 197.1 mm

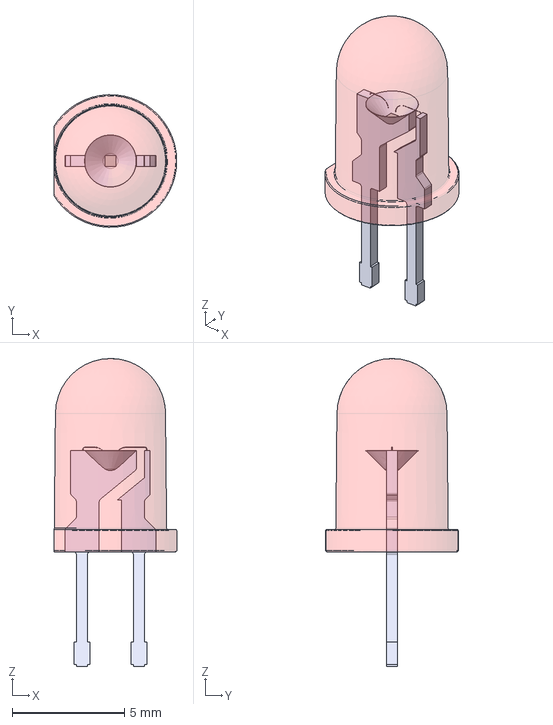
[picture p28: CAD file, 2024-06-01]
Enclosure Design/LED D5 - Red-Clear_cutted conceptual.step
5.45 x 5.90 x 13.7 mm

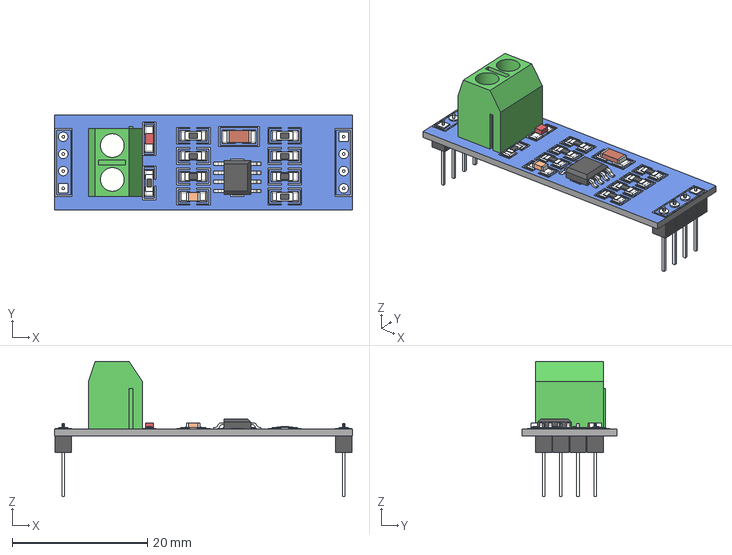
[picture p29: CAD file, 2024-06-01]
Enclosure Design/rs485 for conseptual.stp
44.0 x 14.0 x 20.0 mm

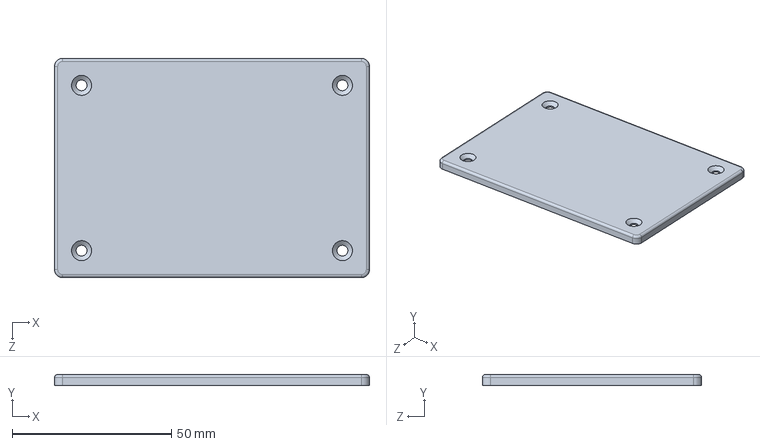
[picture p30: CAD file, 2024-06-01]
Enclosure Design/Lid for the final design.SLDPRT
98.8 x 3.50 x 68.8 mm

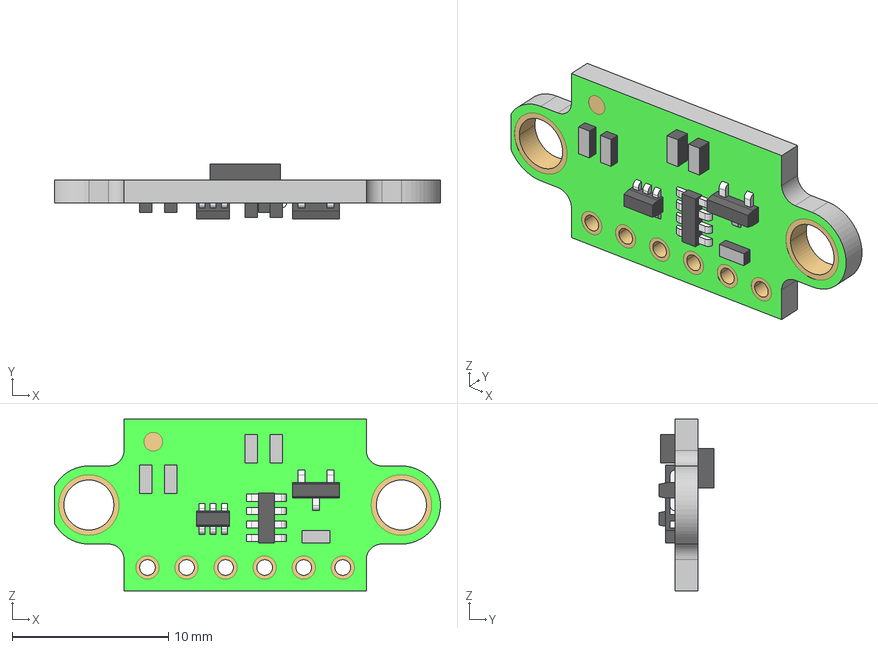
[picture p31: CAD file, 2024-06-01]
Enclosure Design/vl53l0x for conceptual.stp
24.7 x 3.50 x 11.0 mm

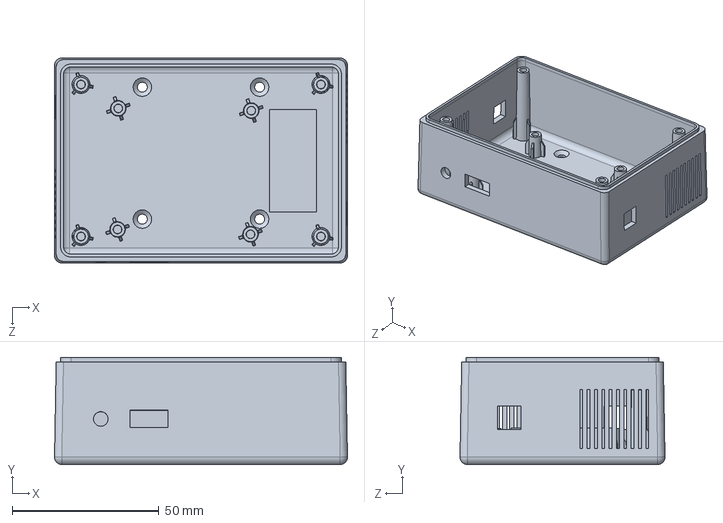
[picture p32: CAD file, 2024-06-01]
Enclosure Design/Box of the gripper.SLDPRT
99.9 x 36.5 x 69.9 mm

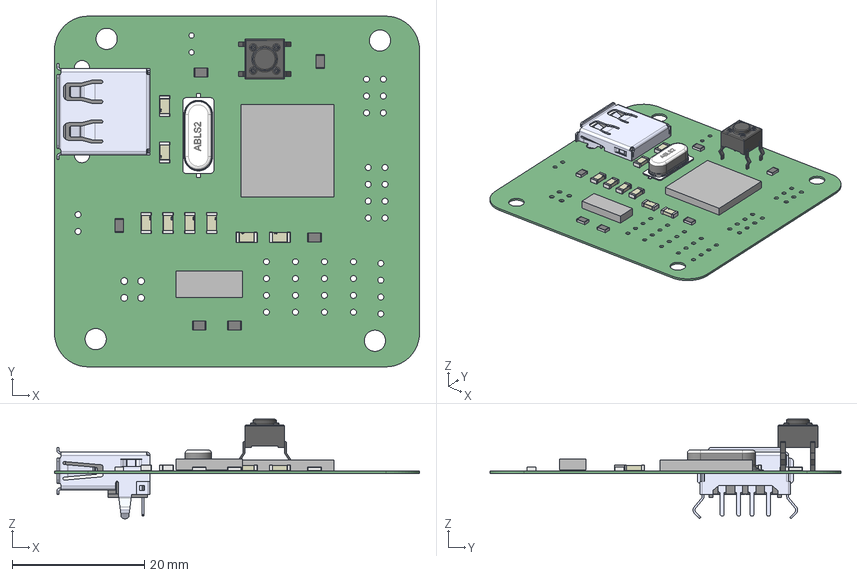
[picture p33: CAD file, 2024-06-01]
Enclosure Design/PCB2 For Conceptual.step
55.1 x 53.0 x 15.0 mm
Mid_Body x 6
Mark x 6
Cap_KEMET_C1206C472K4RACTU_eec x 24
Extruded x 2
Switch_C&K_PTS645SM43SMTR92LFS_eec

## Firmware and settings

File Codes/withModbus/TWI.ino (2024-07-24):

void i2c_init() {
    // Set the clock speed
    TWSR = 0x00;
    TWBR = ((F_CPU/400000)-16)/(2*pow(4,(TWSR&((1<<TWPS0)|(1<<TWPS1)))));
}

void i2c_start() {
    // Send start condition
    TWCR = (1 << TWSTA) | (1 << TWEN) | (1 << TWINT);
    while (!(TWCR & (1 << TWINT)));
}

void i2c_stop() {
    // Send stop condition
    TWCR = (1 << TWSTO) | (1 << TWEN) | (1 << TWINT);
}

void i2c_write(uint8_t data) {
    // Write data to the I2C bus
    TWDR = data;
    TWCR = (1 << TWEN) | (1 << TWINT);
    while (!(TWCR & (1 << TWINT)));
}

uint8_t i2c_read_ack() {
    // Read data from the I2C bus with acknowledgment
    TWCR = (1 << TWEN) | (1 << TWINT) | (1 << TWEA);
    while (!(TWCR & (1 << TWINT)));
    return TWDR;
}

uint8_t i2c_read_nack() {
    // Read data from the I2C bus without acknowledgment
    TWCR = (1 << TWEN) | (1 << TWINT);
    while (!(TWCR & (1 << TWINT)));
    return TWDR;
}
